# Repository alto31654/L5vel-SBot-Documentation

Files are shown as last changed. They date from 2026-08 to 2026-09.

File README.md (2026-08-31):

# L5vel-SBot-Documentation
This is my documentation of the work I have done on the SBots, including assembly guides, costs, set up guides, and 3D models

SUMMER SUMMARY:
For this summer semester, I had began new configurations for the SBOT's, including 1 arm with lift, dual arm, and 3 arm configurations. I have also retrofitted the first Sbot to have a lift.
I created an alternate version of the 3 arm base that is ready for assembly. I have also been working on improving the SetUp.md file within the SBot files to cover any missing steps
or to add in steps to do when certain issues arise. I have created assembly guides on how to build the robots from the ground up and how to configure the components within it.
I have also been developing the physical aspects of two bumper systems - one that is just a 3D printable cushion that goes on the corners of the robot, and one that detects when an impact occurs to actiate the E-Stop in the driving motors.
In my spare time, I am developing a shroud for the XArm 850s that will contain the wires for the external cameras and researching how to route the camera data through the arm itself to remove the reason for the shrouds in the first place.
I have also briefly worked with learning how to write code for a sensor I was trying to implement for the bumper; however, we ended up using a different sensor that doesn't need as much code.

There will be a file tree for each SBot's configuration assembly guide (i.e. single arm, dual arm, single arm with a lift, etc).
These are still a WIP

The CAD folder will contain all CAD files for all configurations of the SBot. This is because multiple configurations use the same parts. 
However there will be a folder for each configuration's assembly file. As of right now, there may be missing part errors when opening assemblies as the files are just copied.
I will reupload the files in a way to automatically fix this issue.
CAD assemblies are a WIP and will change with time.
Final versions of the Assembly Guides will include GitHub links to CAD files.

The cost breakdown sheet will continue to update as the project continues. Final versions of the Assembly Guides will include an appendix to incorporate this into one file.

The PC/Linux set up guide is a WIP and will be included in final versions of the Assembly Guides

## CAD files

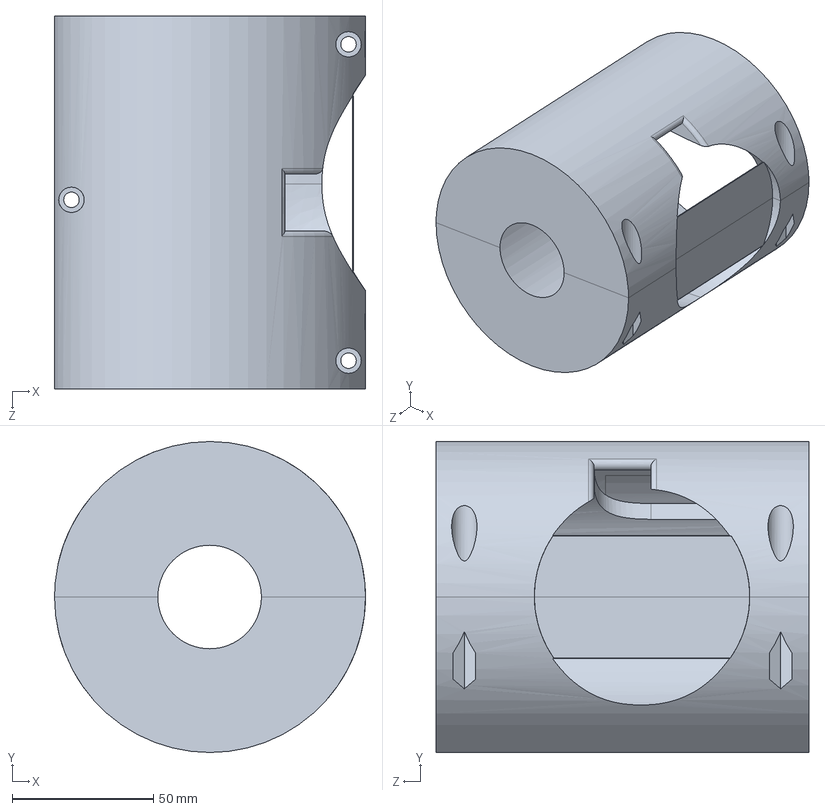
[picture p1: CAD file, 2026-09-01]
SBOT CAD Current/SBOT CAD Current/XArm850/J6CoverWhole.SLDPRT
110.0 x 110.0 x 131.9 mm

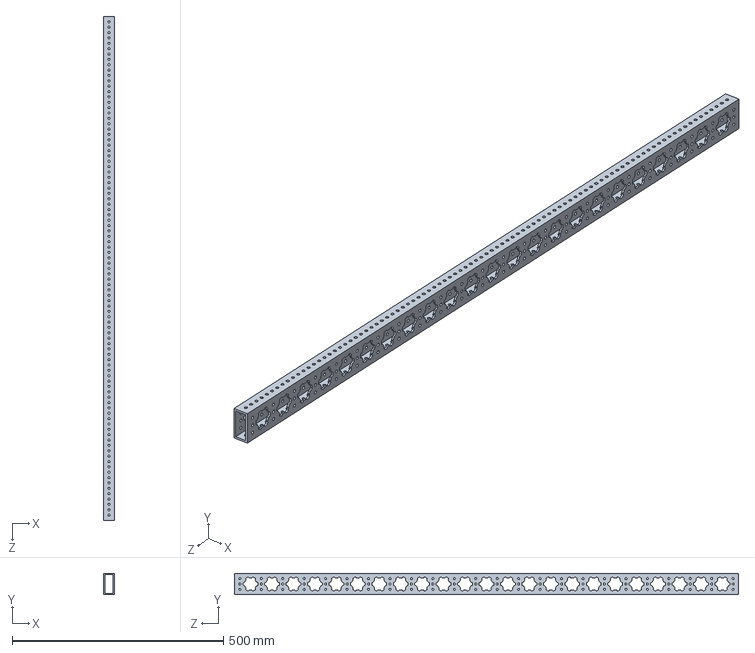
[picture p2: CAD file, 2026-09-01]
SBOT CAD Current/SBOT CAD Current/Hardware/MAXTube whole.STEP
25.4 x 50.8 x 1193.8 mm

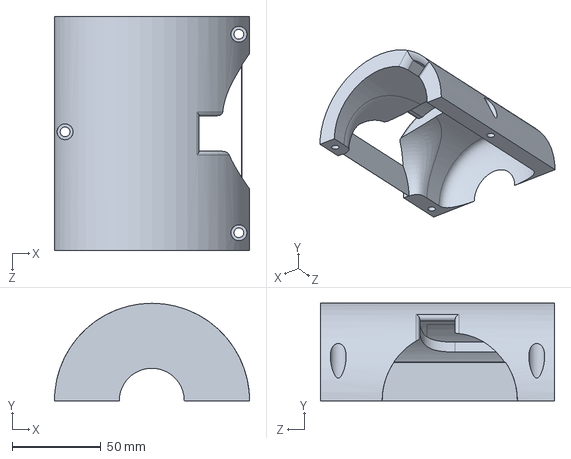
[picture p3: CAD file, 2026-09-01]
SBOT CAD Current/SBOT CAD Current/XArm850/J6Cover1WHoles.SLDPRT
110.0 x 55.0 x 131.9 mm

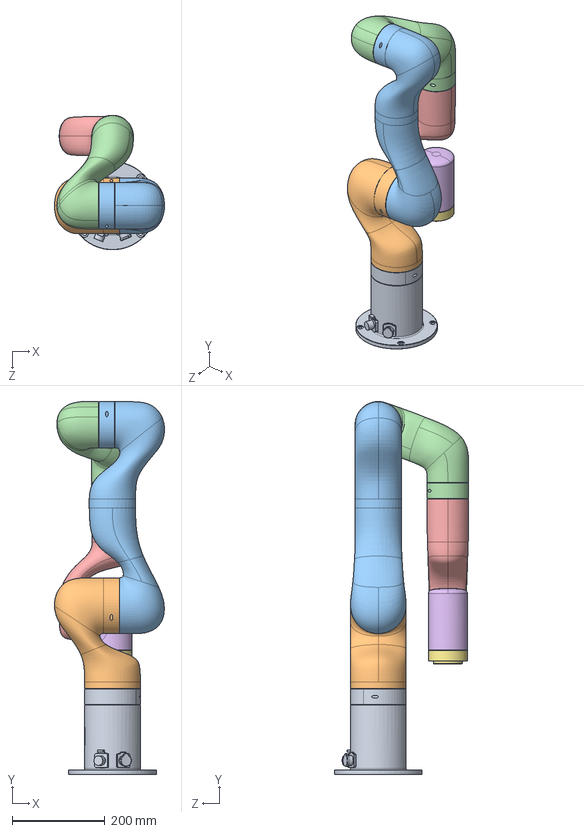
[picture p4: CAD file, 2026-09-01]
SBOT CAD Current/SBOT CAD Current/XArm850/UFACTORY-850-FX85xx-solidworks2016/FX85_M.SLDASM
237.2 x 804.1 x 289.8 mm
FX85_P01
FX85_P02
FX85_P03
FX85_P04
FX85_P05
FX85_P06
FX85_P07

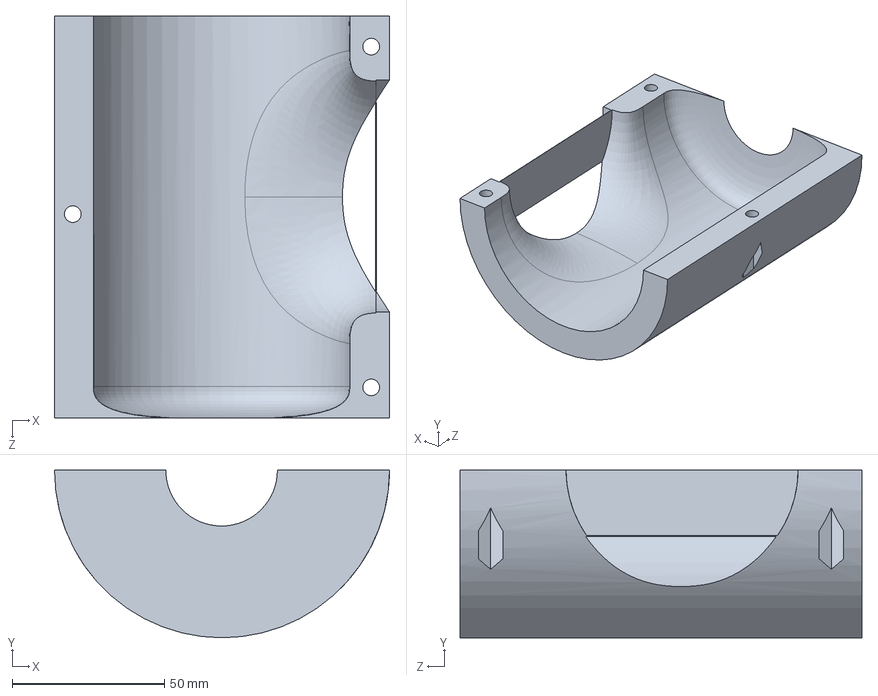
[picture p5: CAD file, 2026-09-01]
SBOT CAD Current/SBOT CAD Current/XArm850/J6CoverWHoles.SLDPRT
110.0 x 55.0 x 131.9 mm

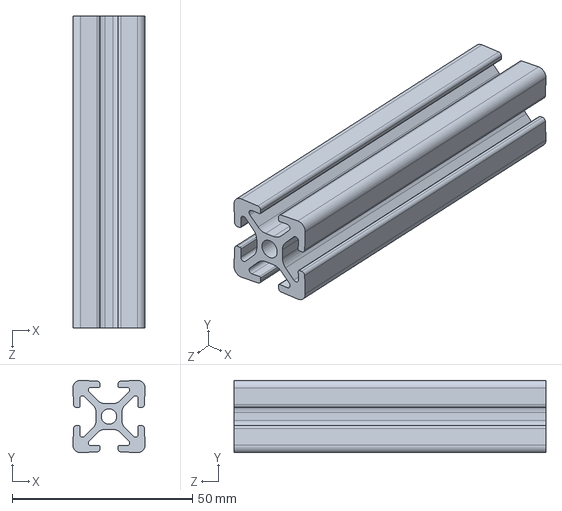
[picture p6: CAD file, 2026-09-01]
SBOT CAD Current/SBOT CAD Current/2020extrusion86_53mm.SLDPRT
20.0 x 20.0 x 86.5 mm

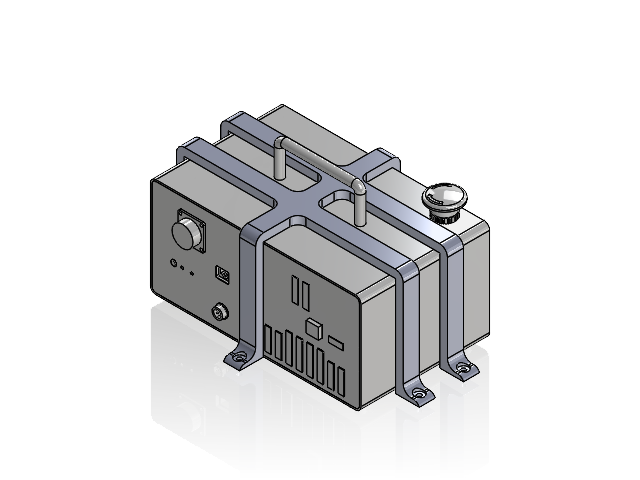
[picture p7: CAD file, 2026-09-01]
SBOT CAD Current/SBOT CAD Current/XArm7/CBMount.SLDASM
AC Control Box Pro(7)
Mount^CBMount

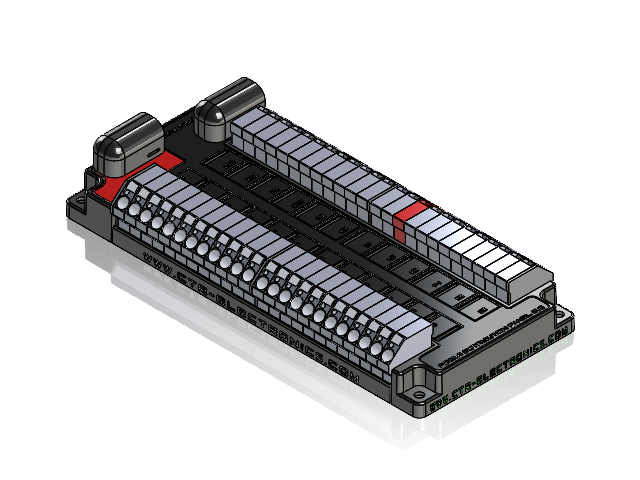
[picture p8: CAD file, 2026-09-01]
SBOT CAD Current/SBOT CAD Current/Hardware/Electronics/PDP 2.0 CAD (1)/PDP_2.0_release.SLDASM
PDP_2.0_NO BREAKERS.STEP
terminal with cover_1.STEP x 2

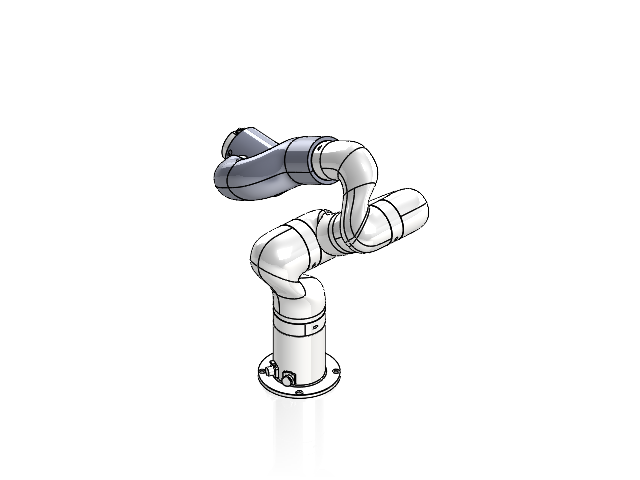
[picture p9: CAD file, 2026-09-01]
SBOT CAD Current/SBOT CAD Current/XArm850/CableCoverAssem.SLDASM
FX85_P01
FX85_P02
FX85_P03
FX85_P04
FX85_P05
FX85_P06
FX85_P07
J6CoverWhole
J5Cover

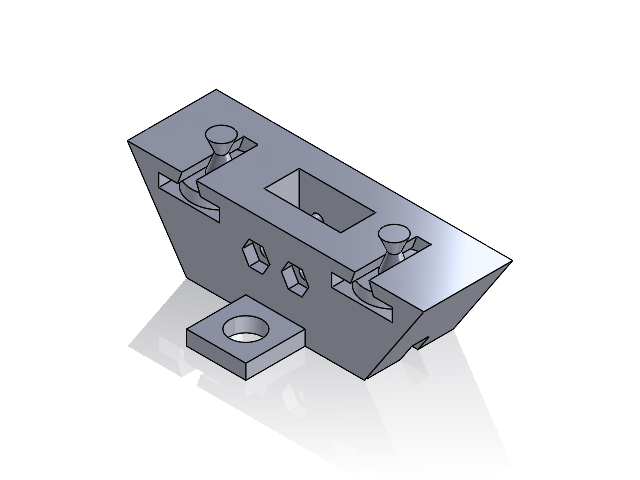
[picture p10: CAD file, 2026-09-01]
SBOT CAD Current/SBOT CAD Current/Hardware/Bumpers/BumpStopAssem.SLDASM
SwitchBumpStop
TPUBumpStop x 2

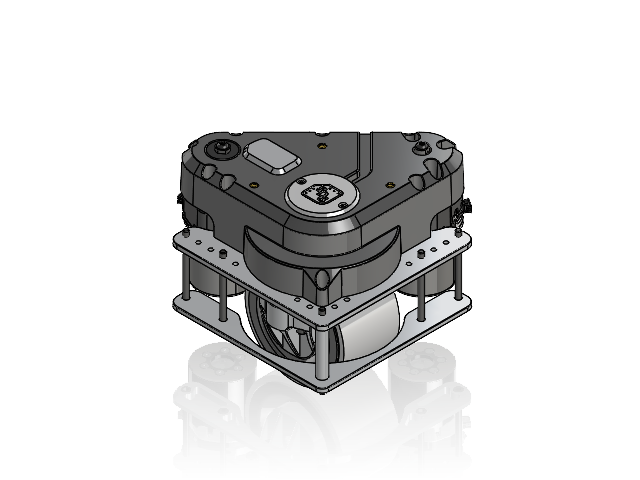
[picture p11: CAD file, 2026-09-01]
SBOT CAD Current/SBOT CAD Current/Hardware/SwerveAssem.SLDASM
MK5i
ISDF-05-D-M_b.STEP x 2
SFSX-RL.STEP x 4
TFM-105-02-L-DH_pins.STEP x 2
TFM-105-02-L-DH_terminal.STEP x 2
USB4110-GF-A_PART1.STEP x 2
REV-11-2159-P01.STEP x 2
REV-11-2159-P11.STEP x 6
REV-11-2159-P02.STEP x 2
REV-11-2159-P04_95893A164.STEP x 4
0.8BTB male 7.5H 2X10P--No side positioning plate.STEP x 2
EVQP7-JA-01P.STEP x 2
REV-11-2159-P09_92832A108.STEP x 16
REV-21-1652-P13.STEP x 2
REV-21-1652-P12.STEP x 6
REV-21-1652-P02.STEP x 2
REV-21-1652-P08.STEP x 2
Screw_M3x5mm_91294A125_Flat_Head_91294A125.STEP x 12
97145A104_Single-Turn Spiral External Retaining Ring_97145A104.STEP x 2
REV-21-1652-P01.STEP x 2
Bearing_17mmID_30mmOD_6656K196_6656K196.STEP x 2
0.8BTB female 9.0H 2X10P - With side positioning plate.STEP x 2
REV-21-1652-P10.STEP x 2
REV-21-3204.STEP x 8
REV-21-2807.STEP x 2
REV-21-2805.STEP x 2

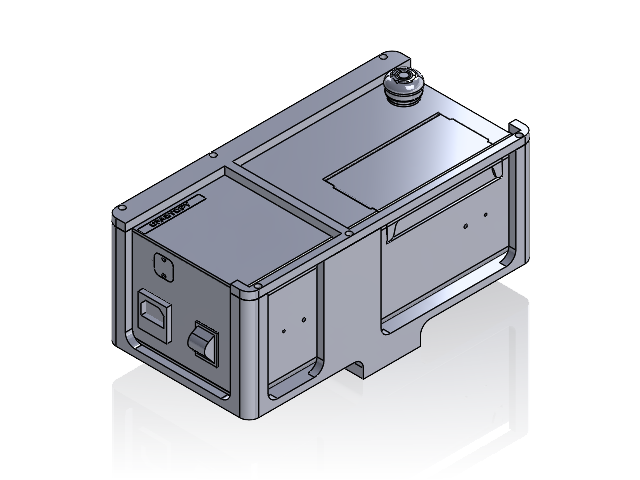
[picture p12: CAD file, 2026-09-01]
SBOT CAD Current/SBOT CAD Current/XArm7/ControlBox7MountAssem.SLDASM
AC Control Box(AC1300)(7)
ControlBox7Holder
CBHolderLid

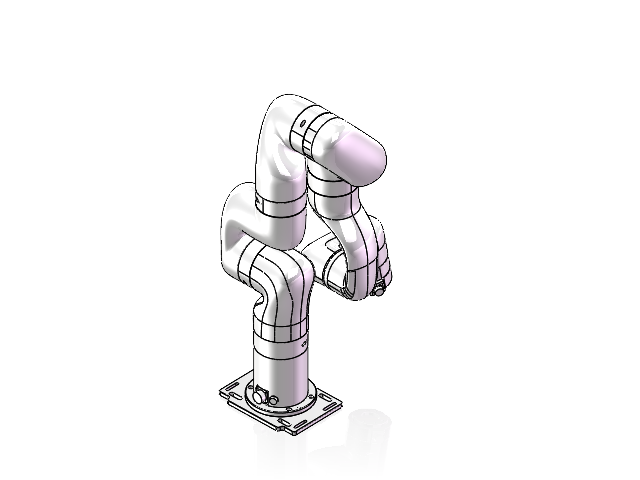
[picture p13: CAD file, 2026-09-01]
SBOT CAD Current/SBOT CAD Current/XArm7/xArm-7-XS1305-solidworks2016/XS1305_M.SLDASM
XS1305_P01
XS1305_P02
XS1305_P03
XS1305_P04
XS1305_P05
XS1305_P06
XS1305_P07
XS1305_P08

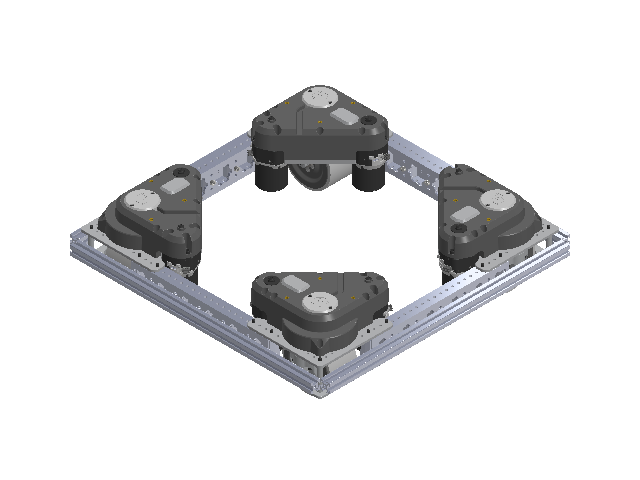
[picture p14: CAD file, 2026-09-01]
SBOT CAD Current/SBOT CAD Current/Hardware/SwerveSquare.SLDASM
MK5i x 4
ISDF-05-D-M_b.STEP x 8
SFSX-RL.STEP x 16
TFM-105-02-L-DH_pins.STEP x 8
TFM-105-02-L-DH_terminal.STEP x 8
USB4110-GF-A_PART1.STEP x 8
REV-11-2159-P01.STEP x 8
REV-11-2159-P11.STEP x 24
REV-11-2159-P02.STEP x 8
REV-11-2159-P04_95893A164.STEP x 16
0.8BTB male 7.5H 2X10P--No side positioning plate.STEP x 8
EVQP7-JA-01P.STEP x 8
REV-11-2159-P09_92832A108.STEP x 64
REV-21-1652-P13.STEP x 8
REV-21-1652-P12.STEP x 24
REV-21-1652-P02.STEP x 8
REV-21-1652-P08.STEP x 8
Screw_M3x5mm_91294A125_Flat_Head_91294A125.STEP x 48
97145A104_Single-Turn Spiral External Retaining Ring_97145A104.STEP x 8
REV-21-1652-P01.STEP x 8
Bearing_17mmID_30mmOD_6656K196_6656K196.STEP x 8
0.8BTB female 9.0H 2X10P - With side positioning plate.STEP x 8
REV-21-1652-P10.STEP x 8
REV-21-3204.STEP x 32
REV-21-2807.STEP x 8
REV-21-2805.STEP x 8
MAXTube Cut x 4
MAXTubeSupport x 28
2020extrusion510mm x 4
SpringLoadedTNut x 12
M5x30mm18-8SocketScrew x 12

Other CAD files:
SBOT CAD Current/SBOT CAD Current/Hardware/CBBracket.SLDASM
SBOT CAD Current/SBOT CAD Current/Hardware/MotorAssem.SLDASM
SBOT CAD Current/SBOT CAD Current/sbotFrame.SLDASM
SBOT CAD Current/SBOT CAD Current/Hardware/Electronics/BatteryWithCornerMounts.SLDASM
SBOT CAD Current/SBOT CAD Current/2020extrusion100mm.SLDPRT
SBOT CAD Current/SBOT CAD Current/2020extrusion84_85mm.SLDPRT
SBOT CAD Current/SBOT CAD Current/Hardware/Brackets/135Bracket.SLDPRT
SBOT CAD Current/SBOT CAD Current/Hardware/Brackets/45Bracket.SLDPRT
SBOT CAD Current/SBOT CAD Current/Hardware/Brackets/CornerBracket.SLDPRT
SBOT CAD Current/SBOT CAD Current/Hardware/Bumpers/BallCornerBumper.STL
SBOT CAD Current/SBOT CAD Current/Hardware/Bumpers/BigCornerBumper.SLDPRT
SBOT CAD Current/SBOT CAD Current/Hardware/Bumpers/BigCornerBumper.STL
SBOT CAD Current/SBOT CAD Current/Hardware/Bumpers/SwitchBumpStop.SLDPRT
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

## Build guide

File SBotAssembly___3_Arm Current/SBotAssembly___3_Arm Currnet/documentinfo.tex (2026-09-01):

%------------------------------------------------
% Document Information
%------------------------------------------------

\newcommand{\DocTitle}{S-Bot Assembly Guide}

\newcommand{\DocSubtitle}{Mechanical Assembly and Configuration Manual}

\newcommand{\DocConfig}{Three Arm Configuration}

\newcommand{\DocNumber}{L5-SB-003}

\newcommand{\DocVersion}{1.0.0}

\newcommand{\DocRevision}{A}

\newcommand{\DocDate}{July 2026}

\newcommand{\Authors}{Johns, William}

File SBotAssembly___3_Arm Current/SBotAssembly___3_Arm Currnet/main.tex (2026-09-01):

\documentclass[11pt]{article}

\input{preamble}
\input{styles}
\input{documentinfo}

\author{}
\date{}

\begin{document}

\input{titlepage}

\pagenumbering{roman}
\tableofcontents
\clearpage

\pagenumbering{arabic}

\input{sections/motor_assembly}
\clearpage

\input{sections/swerve_module}
\clearpage

\input{sections/motor_setup}
\clearpage

\input{sections/power_distribution}
\clearpage

\input{sections/canivore}
\clearpage

\input{sections/base_bottom}
\clearpage

\input{sections/base_middle}
\clearpage

\input{sections/base_top}
\clearpage

\appendix
\input{appendices/motor_config_appen}

\end{document}

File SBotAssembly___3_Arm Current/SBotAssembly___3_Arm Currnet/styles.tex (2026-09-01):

% Colors
\definecolor{sbotblue}{HTML}{1F4E79}
\definecolor{sbotlightblue}{HTML}{EAF3FA}
\definecolor{sbotgray}{HTML}{F4F4F4}

% Callout boxes
\newtcolorbox{partsbox}{
colback=sbotlightblue,
colframe=sbotblue,
title=Required Parts,
fonttitle=\bfseries
}

\newtcolorbox{warningbox}{
colback=yellow!10,
colframe=orange!80!black,
title=Important,
fonttitle=\bfseries
}

\newtcolorbox{tipbox}{
colback=sbotgray,
colframe=gray,
title=Tip,
fonttitle=\bfseries
}

\titleformat{\section}
{\Large\bfseries\color{sbotblue}}
{\thesection}{0.75em}{}
[\titlerule]

\titleformat{\subsection}
{\large\bfseries\color{sbotblue}}
{\thesubsection}{0.75em}{}

% Better spacing
\setlength{\parindent}{0pt}
\setlength{\parskip}{6pt}
\setlist[itemize]{topsep=3pt,itemsep=2pt}

% Headers/footers
\pagestyle{fancy}
\fancyhf{}
\lhead{S-Bot Assembly Guide}
\rhead{\leftmark}
\cfoot{\thepage}

% Image safety
\makeatletter
\def\maxwidth{\ifdim\Gin@nat@width>\linewidth\linewidth\else\Gin@nat@width\fi}
\def\maxheight{\ifdim\Gin@nat@height>0.85\textheight 0.85\textheight\else\Gin@nat@height\fi}
\makeatother
\setkeys{Gin}{width=\maxwidth,height=\maxheight,keepaspectratio}

%------------------------------------------------
% Table of Contents Styling
%------------------------------------------------

\renewcommand{\contentsname}{Table of Contents}

\setlength{\cftbeforesecskip}{6pt}
\setlength{\cftbeforesubsecskip}{2pt}

\renewcommand{\cftsecfont}{\bfseries\color{sbotblue}}
\renewcommand{\cftsecpagefont}{\bfseries\color{sbotblue}}

\renewcommand{\cftsubsecfont}{\normalfont}
\renewcommand{\cftsubsecpagefont}{\normalfont}

\renewcommand{\cftsecleader}{\cftdotfill{\cftdotsep}}

%------------------------------------------------
% Assembly Step Styling
%------------------------------------------------

\newcounter{assemblystep}

\newcommand{\resetassemblysteps}{%
    \setcounter{assemblystep}{0}
}

\newcommand{\assemblystep}[1]{%
    \refstepcounter{assemblystep}
    \vspace{0.6cm}
    {\large\bfseries\color{sbotblue}Step \theassemblystep: #1\par}
    \vspace{0.15cm}
    \noindent\color{sbotblue}\rule{\textwidth}{0.5pt}
    \color{black}
    \vspace{0.25cm}
}

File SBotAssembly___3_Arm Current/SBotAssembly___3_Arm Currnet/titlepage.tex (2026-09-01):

\begin{titlepage}

\thispagestyle{empty}
\centering

%------------------------------------------------
% Top spacing
%------------------------------------------------

\vspace*{1.5cm}

%------------------------------------------------
% Title
%------------------------------------------------

{\Huge\bfseries\color{sbotblue}\DocTitle\par}

\vspace{0.35cm}

{\Large\DocSubtitle\par}

\vspace{0.25cm}

{\Large\bfseries\color{sbotblue}\DocConfig\par}

\vspace{0.75cm}

\color{sbotblue}
\rule{0.8\textwidth}{1.5pt}
\color{black}

\vspace{1cm}

%------------------------------------------------
% Robot Image
%------------------------------------------------

% Uncomment once you have a good image
%
% \includegraphics[width=0.70\textwidth]{images/sbot_overview.png}
%
% OR use your CAD render instead

\vfill

%------------------------------------------------
% Document Information
%------------------------------------------------

\renewcommand{\arraystretch}{1.4}

\begin{tabular}{rl}
\textbf{Document ID:} & \DocNumber \\
%\textbf{Configuration:} & \DocConfig \\
\textbf{Version:} & \DocVersion \\
%\textbf{Revision:} & \DocRevision \\
\textbf{Date:} & \DocDate \\
\textbf{Written by:} & \Authors \\
\end{tabular}

%\vfill

{\Large L5VEL}

\vspace{0.3cm}

%{\small Internal Documentation}

\end{titlepage}

\clearpage

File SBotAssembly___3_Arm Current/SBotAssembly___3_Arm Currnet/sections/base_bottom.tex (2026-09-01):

\section{Base Assembly -- Bottom Layer}
\resetassemblysteps

\begin{partsbox}
\begin{minipage}[t]{\linewidth}
\vspace{0pt}
\begin{itemize}
\item
  4 Assembled Swerve Modules
\item
  1
  \href{https://www.bestbuy.com/product/anker-solix-c1000x-gen2-portable-power-station-2000w-1024-wh-capacity-dark-gray/JJ858RLLVK}
  {Anker Solix C1000x Gen 2}
\item
  1 A/C Control Boxes
\item
  2 \href{https://www.revrobotics.com/MAXTube-2x1/}
  {2"x1"x47" - 1/8" MAXTube Channel} -
  \href{https://revrobotics.com/content/cad/REV-21-3580.STEP}{STEP}
\item
  1 \href{https://www.revrobotics.com/maxtube-internal-supports/}
  {30 pack MAXTube Internal Support} -
  \href{https://revrobotics.com/content/cad/REV-21-3620.STEP}{STEP}
\item
  10
  \href{https://www.amazon.com/Aluminum-Extrusion-European-Standard-Anodized/dp/B0CJ2444RP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\&dib=eyJ2IjoiMSJ9.PZ2FPe9mMeh2RjmXCOARMJXrWmDwBK7v6pNs8rNSyqoPpPKsgh7tF6KNxYk9Ar6jRMz0ZAwxM4tbQfzEnDNLSBNuQv6MKW9yA_1ZpzTuvs6cmNikscEC3qR-9UYQdLuWI9VPNDXBrewSK4GJfKpK7OGRP678XPT5gkdxunE0mi17g96SjQU3kdsGpMGbod45Zct9aVPBfKQaI-vDfUCWijtkFxV_eApHlAQB2atX4vw.g0drfgF2Qlq6SmjnSINZo8Rp1Ej7S_yfQs0q05EGSqg\&dib_tag=se\&keywords=10\%2Bpcs\%2B800mm\%2BT\%2BSlot\%2B2020\%2BAluminum\%2BEXtrustion\%2BEuropean\%2BStandard\%2BAnodized\%2BLinear\%2BRail\%2BPENGLONG\&nsdOptOutParam=true\&qid=1780009034\&sprefix=10\%2Bpcs\%2B800mm\%2Bt\%2Bslot\%2B2020\%2Baluminum\%2Bextrustion\%2Beuropean\%2Bstandard\%2Banodized\%2Blinear\%2Brail\%2Bpenglong\%2Caps\%2C105\&sr=8-2\&th=1}
  {20x20x800mm T-Slot Aluminum Extrusion}
  \item
  1
  \href{https://a.co/d/00U2xDgu}
  {2x1x12" Aluminum Extrusion}
\item
  8
  \href{https://www.amazon.com/2020-Bracket-Aluminum-Extrusion-Connector/dp/B0B15LWB96/ref=sr_1_4?crid=GBX1DKP7GAGY\&dib=eyJ2IjoiMSJ9.YwZZJkrg4tHSDQtAhQFm_xWTziZvc73fSAx6Xu3V0eU9Pqt2kpgHOMdfl-j03eXqLr9SqVJYsOjBRsPwTCeRLPtVxaWp92QOj3YkpEqxe_f8uoBLlCDSbJNoPuO7oEmj38Xk2B-rbRdMmVb4LCTjK_d-28hle0DLks3O0dHpkuvaCBjan9vx2tdJSw9iC-mnxOK3t7UgCEoea3K5irfrMBFTM5oumf1ZcDhywTPPYWw._AcCkrgnzVeJorywdvUhORfM7Ll_8HjaW-XAmTmjHmU\&dib_tag=se\&keywords=10\%2Bpcs\%2B2020\%2Bcorner\%2Bbracket\%2Bjoint\%2Bplate\%2Bbaykailin\&nsdOptOutParam=true\&qid=1780009641\&sprefix=10\%2Bpcs\%2B2020\%2Bcorner\%2Bbraket\%2Bjoint\%2Bplate\%2Bbaykailin\%2Caps\%2C145\&sr=8-4\&th=1}
  {L Shape Corner Plates}
\item 
  4
  \href{https://a.co/d/06DF40PH}
  {T Shape Plates}
\item
  16
  \href{https://www.amazon.com/32Pcs-Bracket-Aluminum-Extrusion-Industrial/dp/B0C19C1G8W/ref=sr_1_2?crid=2ZFRAXDPV6K9C\&dib=eyJ2IjoiMSJ9.9llDtPZ6rC_p4rDCn1uyFMxeYyRqWBqgLth9R1QRUb9haw9tHsyhizxJVyQVEJX5E5PHdfHeTqni3lrNDXwIjGCy2CiyC60eyHkbztAObX37nNxon_ILhSnd09eTZLvc84vumvQUyfKhNQYpPDhZgRcfddb-_4-e74BTyMMXhbZpMVmt0jbXza8zo7j_JoYYlt-aRjExxcLoMb4P7yTEhUpbAyACgTkJjVQYmn20FDY.kABSI1pFjrAhVJf0W1q_K6ofkuv8qBnGbZljKoPPBOA\&dib_tag=se\&keywords=32\%2Bpcs\%2Bcorner\%2Bbracket\%2B(20x17)\%2B2020\%2BNVAXQF\&qid=1780009800\&sprefix=32\%2Bpcs\%2Bcorner\%2Bbracket\%2B20x17\%2B2020\%2Bnvaxqf\%2Caps\%2C154\&sr=8-2\&th=1}
  {Corner Brackets}
\item 
  2
  \href{https://a.co/d/04PJysob}
  {45\textdegree/135\textdegree Angle Brackets} 
\item
  4
  \href{https://www.amazon.com/Connector-European-Standard-Aluminum-Extrusion/dp/B08C9Q2TGW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\&dib=eyJ2IjoiMSJ9.XlFn0FUD_8bCmwRRsrK3ogoBM9pDYnXxPWb7pYhDUtpbaBdLS8JCgUwpbQRowJIBRGu7SUeTHqtP1eBtSTiS18Sg84w_ihJPsVWvAMiteSHIzFL2oHRrPM4m8CAJ-ks8sh8j5DC-wP7l_XGKElRn3GHssF1H0BJaBYMlbejWc5FgyIl1I2W_iTsWiMzd4AI7nCJLSuzAJ6M40i4CYv-TYfnSxv07gNfMx5ZabKKs8aw.XCs7Hk74AdpQPvURhkJcwiumf4aajQdL3EV2vXkkcQc\&dib_tag=se\&keywords=8pcs\%2B2020\%2Baluminum\%2Bextrustion\%2Bt\%2Bslot\%2Bcorner\%2Bbracket\%2B3\%2Bway\%2Btri\%2Bconnector\%2BBLCCLOY\&nsdOptOutParam=true\&qid=1780010034\&sprefix=8pcs\%2B2020\%2Baluminum\%2Bextrustion\%2Bt\%2Bslot\%2Bcorner\%2Bbracket\%2B3\%2Bway\%2Btri\%2Bconnector\%2Bblccloy\%2Caps\%2C121\&sr=8-3\&th=1}
  {Tri-Connectors}
\item
  118
  \href{https://www.amazon.com/100-Pack-Aluminum-Extrusions-Profile-Accessories/dp/B07VHNGBWJ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\&dib=eyJ2IjoiMSJ9.5erSjcFGuqxSi7i2L21rT0vbw0ytuhxrp2ltZMOLJ8UqIwudlyaYHt6ZpRlbWvk8FE864dYDJ1VLjjJk06LhvL07sQfFYWLzdZL2KVXkDSPyUpj40WzXATJ8pfYO-zARlj70J7cKX5n7kSFpZu9gwaq8QH-tRelX3ksKgh7TlIR0J96mfletc1Kltj1N9UXhiUmpMmKqw3YiYb35hBPuc4xUwdT7UsevWwIn2pnDoC0.3xr-5AQMwqWdX2mbf9nYZ-dcUiSk-N2MZR-ugnD5pTw\&dib_tag=se\&keywords=100-pack\%2B2020\%2Broll\%2Bin\%2Bspring\%2Bloaded\%2Bt\%2Bnut\%2Bm5\%2BPOLISI3D\&nsdOptOutParam=true\&qid=1780010876\&sprefix=100-pack\%2B2020\%2Broll\%2Bin\%2Bspring\%2Bloaded\%2Bt\%2Bnut\%2Bm5\%2Bpolisi3d\%2Caps\%2C142\&sr=8-3\&th=1}
  {Spring Loaded M5 T-Nuts}
\item
  82
  \href{https://www.amazon.com/SVLING-175PCS-Button-Socket-Spanner/dp/B0FY5V1MPV/ref=sr_1_3?crid=GD2UCGPO1OVK\&dib=eyJ2IjoiMSJ9.tz2hSSl2Ko7I26DlEqA0mgjFOTYWZVyXkZOq0TCaByptr6KbeIy5LjmCNKtSxXotJ40yMGtu911TcFvMq0lGVkDBizgWGzuMKf9cWYvgSg6MYah47H1GVJieTB7XXt9ff_UrymOopVPVZhsQ43j2CPIbsql8_NvrnjpWMGIhZEjiU2ySpVBKEtTZuLau4a4svmc2pzIAvlywjPajTNJJAWlpVt8YTIPqh1EQDcE9mJ0.i4abLXgOdvPijXQszcI-ovrsFf_kOuUGIbLAR9xh9WA\&dib_tag=se\&keywords=m5x8mm\%2B175pcs\%2Bbutton\%2Bhead\%2Bsocket\%2Bcap\%2Bscrew\%2Bbolts\%2BSVLING\&nsdOptOutParam=true\&qid=1780011697\&sprefix=m5x8mm\%2B175pcs\%2Bbutton\%2Bhead\%2Bsocket\%2Bcap\%2Bscrew\%2Bbolts\%2Bsvling\%2Caps\%2C128\&sr=8-3\&th=1}
  {Button Head M5x8mm Machine Screws}
\item
  22
  \href{https://a.co/d/0beRFsAu}
  {Button Head M5x10mm Machine Screws}
\item
  12 
  \href{https://www.mcmaster.com/91292a192/}
  {M5x30mm Machine Screws}
\item
  4
  \href{https://a.co/d/0hDeyVaw}
  {M5x55mm Socket head Machine Screws} 
\item
  8 M5 Washers
\item
  2 M5 Nuts
\item
  1
  \href{https://www.amazon.com/Loctite-242-Threadlocker-Liquid-1-69oz/dp/B002P8LQ1C/ref=sr_1_4?crid=1C7SLWXA3HNCF\&dib=eyJ2IjoiMSJ9.7OmIx_oDHsONqWbeidNiSrahsI0Km1SsrNH3D-gyuZNfhTT6fuPz-yxpn6ouyWCmNM6CYg6vC_Vwy65nIwSK1Zk51und6wQn-HBHnxvXSz_HK_Ug496ZmvlwSMH0ThO-fFtpz10DXtIVyznYEHlvFjtMq0vzz7dSyhbQaQ1VxxJAWf0jfW4wgc0CZbspWrNj9wj5RVRE5bh1iz6qJ_w8ki7GWFobgrXoJeNJ2M0ao4LMAlM5zlhJxdQqxtc9te0Q7sO6Vhc9_SeBVJMOXptmM-4TMQdzEPjVM4bTiYMuMtw.KKRsu1AubScYRtEjyD0dvZ9Ou056x5yyAdyc4josUng\&dib_tag=se\&keywords=Loctite+242\&qid=1780011409\&sprefix=loctite+242\%2Caps\%2C172\&sr=8-4}
  {Bottle Loctite}
\item
  2
  \href{https://www.amazon.com/Fondwell-Adjustable-Reinforced-Internal-Tie-Downs/dp/B0CC55TP9P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\&dib=eyJ2IjoiMSJ9.tKxN_u-fARPeq3NN7oKUvKFmazhBJgR5wCeEcW3RRpU.Z9UEwgguOvz_g9mCpK3gWCWXdqGQbj6VpLNOE-pqfa4\&dib_tag=se\&keywords=Fondwell\%2Bhigh-quality\%2B1\%2F8\%22rope\%2Bhangers\&qid=1780012484\&sprefix=fondwell\%2Bhigh-quality\%2B1\%2F8\%2Brope\%2Bhangers\%2Caps\%2C116\&sr=8-1\&th=1}{1/8''
  Ratcheting Rope Hangers}

\end{itemize}
\end{minipage}
\end{partsbox}

\assemblystep{Prepare the 2x1 Channels}
Cut the 2x1 MAXTube to 288mm. The outer most edge of the holes on the 1
inch side of the channel should be 1.5mm away from the edge with a 0.5mm
tolerance. The larger holes on the 2 inch side will be at the start and
end of the piece of the channel. The edge of these holes will most
likely be cut off. Insert 7 internal support pieces, 1 on each end and 1
at each set of holes on the 2'' side.

\begin{figure}[H]
\centering
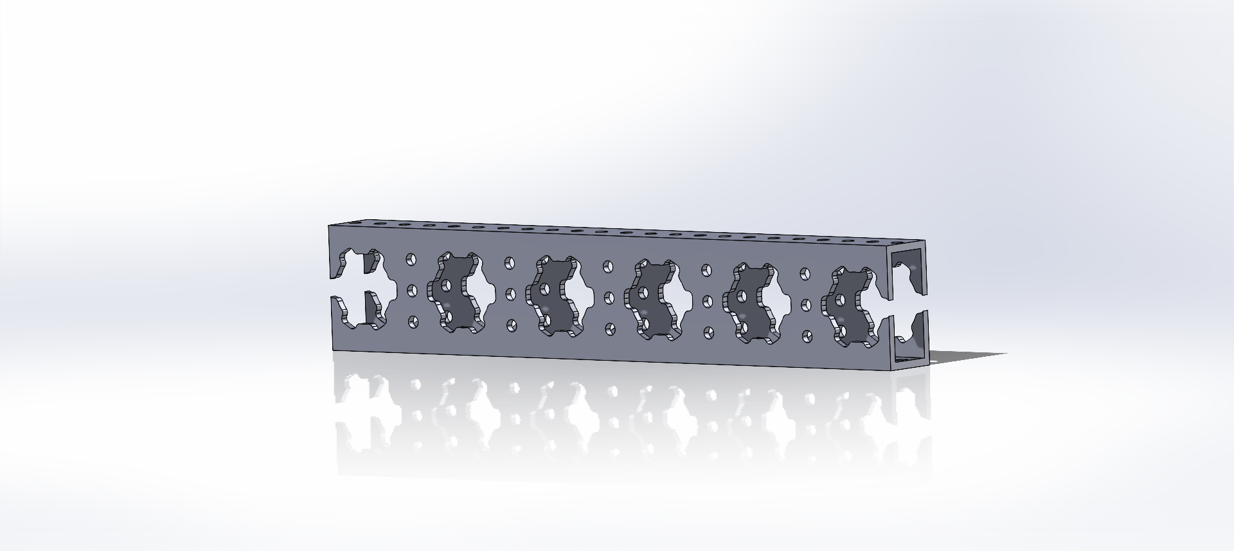
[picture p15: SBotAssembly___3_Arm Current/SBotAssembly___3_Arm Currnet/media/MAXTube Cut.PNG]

\hfill
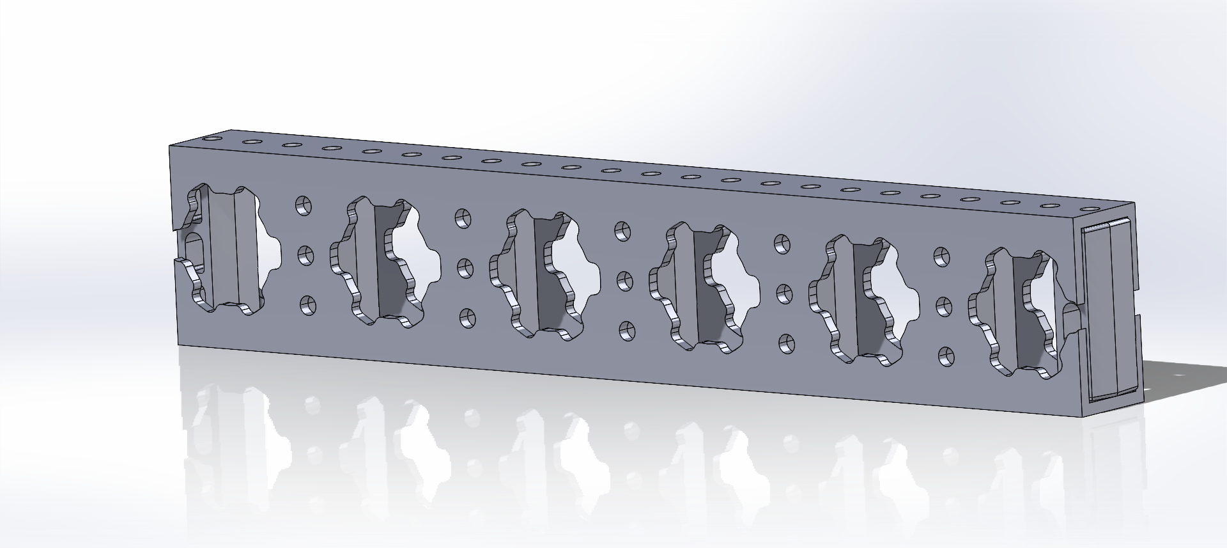
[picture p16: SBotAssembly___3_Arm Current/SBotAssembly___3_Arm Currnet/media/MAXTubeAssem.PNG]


\caption{The cut 2×1 MAXTube with internal supports seated at each end and hole set.}
\end{figure}

\assemblystep{Build the Base Frame}
Place 3 T-Nuts in one side of 4 508mm extrusions. Add a
drop of Loctite to the end of 3 30mm screws and attach the 2x1 channel
using the center three sets of holes. Do not tighten until the base is
properly aligned. Repeat these steps 3 more times.

\begin{figure}[H]
\centering
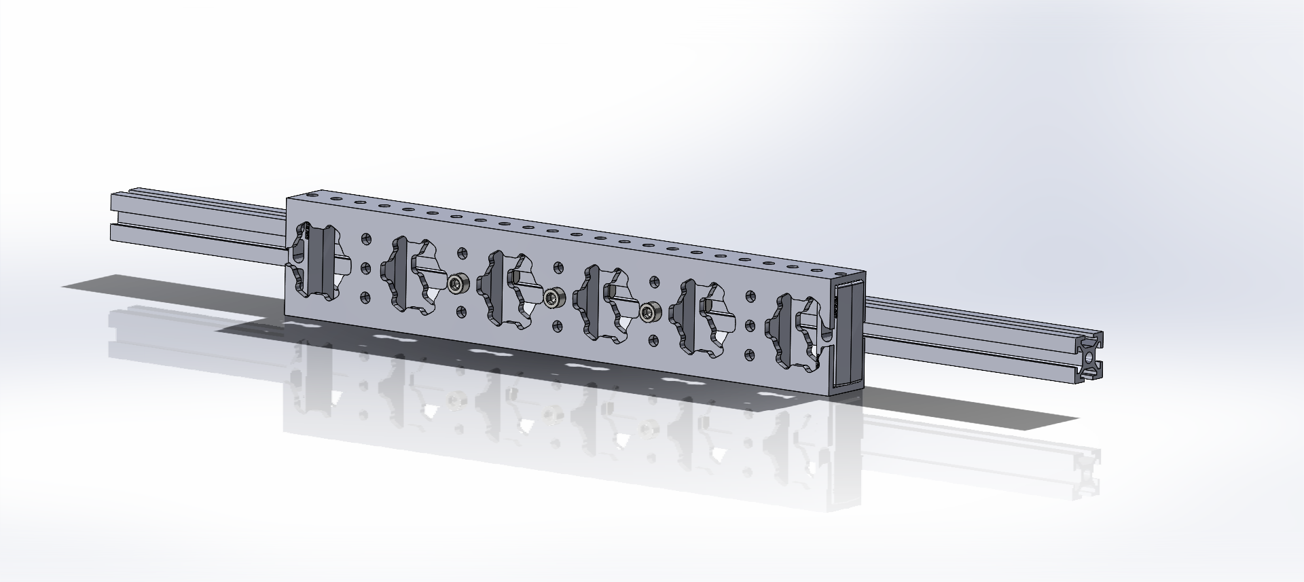
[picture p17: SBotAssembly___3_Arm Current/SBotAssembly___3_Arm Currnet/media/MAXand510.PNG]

\caption{Attaching a 20x20mm extrusion to the 2x1 channel through the
center hole sets.}
\end{figure}

\assemblystep{Mount the Swerve Modules}
Remove the 2 long bolts on each side of the swerve modules and slide the
2x1 channel between the two plates. Secure with the bolts that were just
removed. Be sure to add Loctite to the ends of these bolts and secure
tightly. Repeat until the modules are assembled in a square. Add the
Tri-Connectors to the 20x20mm extrusions with the 2-pronged side facing
upwards.

\begin{figure}[H]
\centering
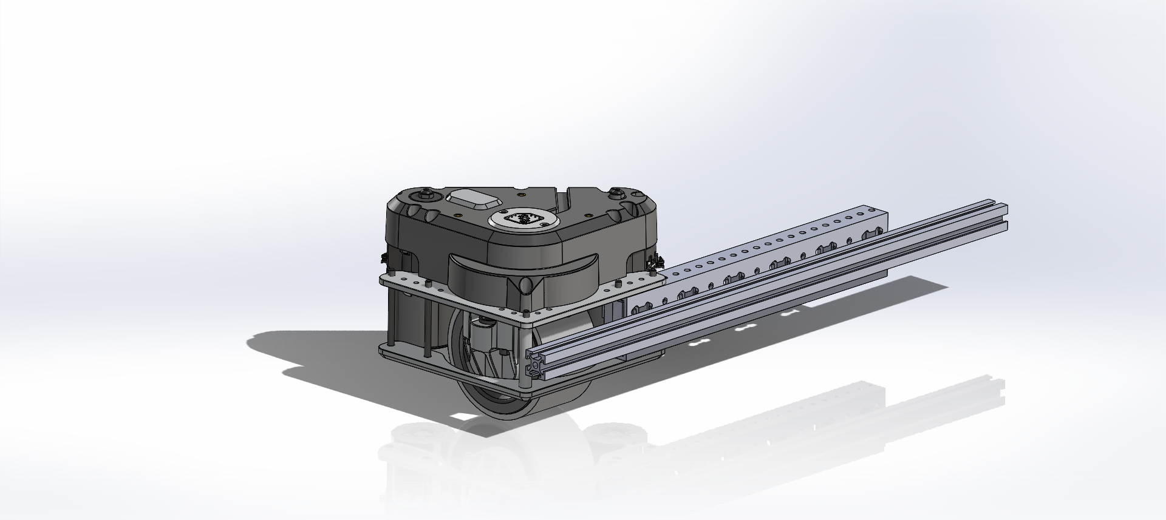
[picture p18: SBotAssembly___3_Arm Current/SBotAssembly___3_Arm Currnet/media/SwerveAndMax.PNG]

\hfill
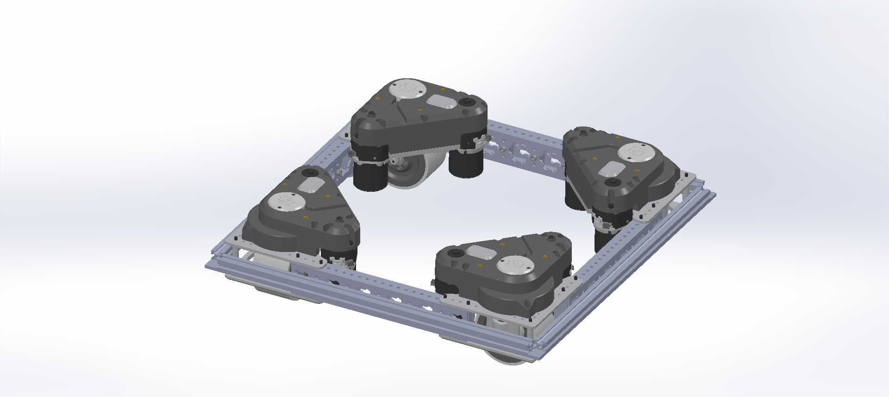
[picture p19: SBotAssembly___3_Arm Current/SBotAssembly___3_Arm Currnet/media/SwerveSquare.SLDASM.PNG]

\caption{Sliding the 2x1 channels between the swerve module plates and
adding the Tri-Connectors.}
\end{figure}

\assemblystep{Install the Vertical Extrusions}
Vertically install 4 400mm extrusions, one at each corner. Tighten the set
screws.

\begin{figure}[H]
\centering
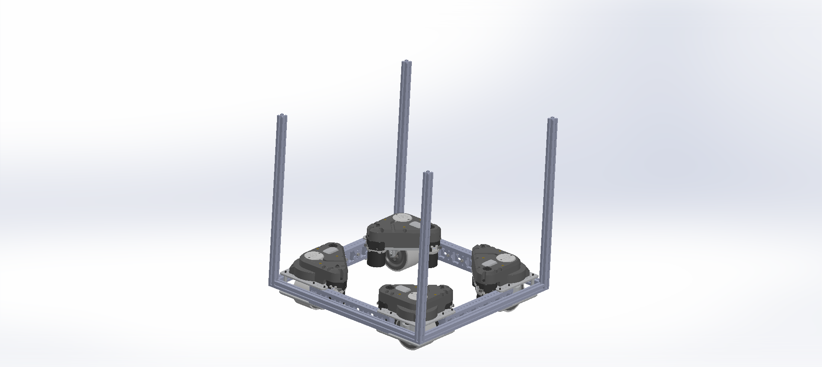
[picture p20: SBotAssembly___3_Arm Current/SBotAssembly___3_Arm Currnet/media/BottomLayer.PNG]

\caption{A vertical 20x20mm extrusion installed at a corner via the
Tri-Connector.}
\end{figure}

Make sure the four extrusions are aligned properly and add the set pins
to the Tri-Connectors. Then tighten the M5x30mm bolts going through the
2x1'' channel.

\assemblystep{Install Corner Brackets}
Install a corner bracket at each 90 degree angle. Each one will use two
T-Nuts and two M5x8mm button head screws. Be sure to secure with
Loctite.

\begin{figure}[H]
\centering

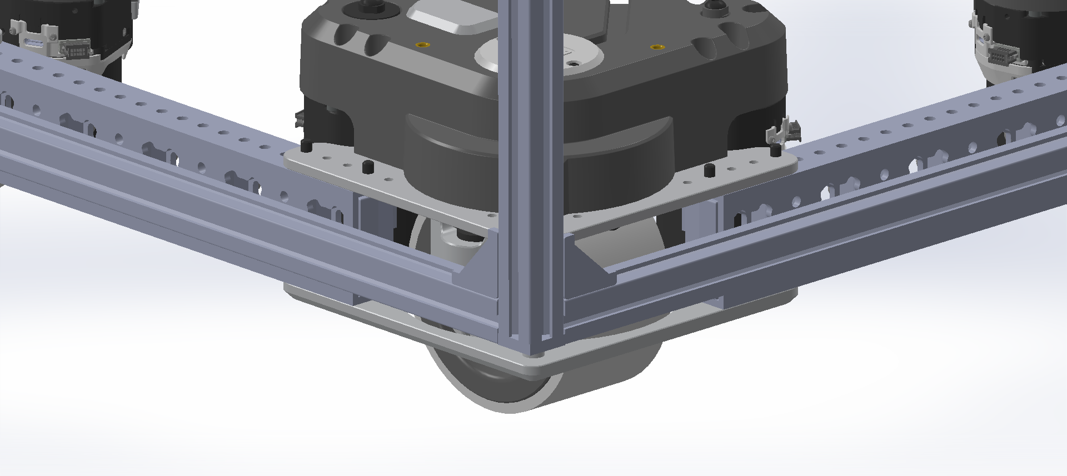
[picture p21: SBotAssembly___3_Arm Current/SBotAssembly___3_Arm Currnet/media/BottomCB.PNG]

\caption{A corner bracket installed at a 90$^\circ$ joint with two T-Nuts
and two button head screws.}
\end{figure}

\assemblystep{Install L-Shape Corner Plates}
Install a L-shape corner plate at each of these locations using 4 T-Nuts
and 4 M5x8mm button head screws. Do not tighten until all 4 screws are
in place. Be sure to secure with Loctite.

\begin{figure}[H]
\centering
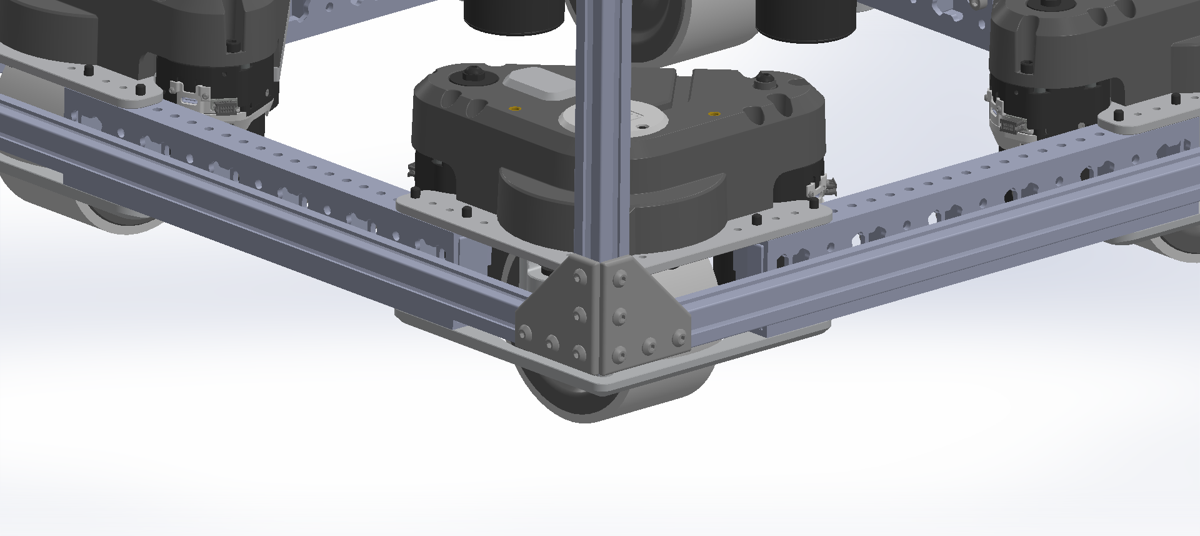
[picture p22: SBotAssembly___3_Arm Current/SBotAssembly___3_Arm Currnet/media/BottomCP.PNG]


\caption{An L-shape corner plate fastened with four T-Nuts and four
button head screws.}
\end{figure}

\assemblystep{Add the Underside Extrusions}
Affix two pieces of 20x20x508 extrusions to the underside of the base
using a T-Nut and a M5x50mm socket head screw on each end. Use the
mounting holes on the inner side of the internal supports of the 2x1"
channels as shown below. Be sure to secure with Loctite.

\begin{figure}[H]
\centering
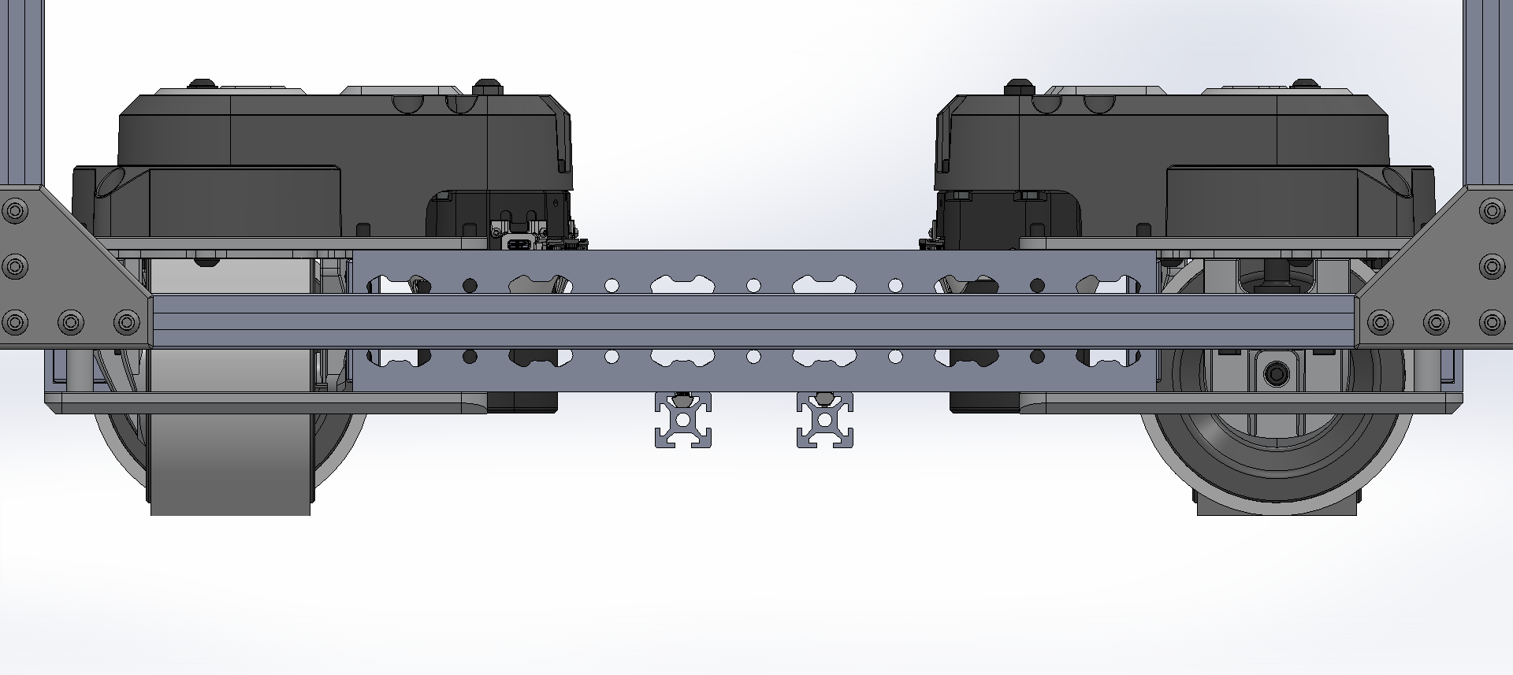
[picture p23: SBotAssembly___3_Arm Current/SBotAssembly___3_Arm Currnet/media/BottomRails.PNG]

\hfill
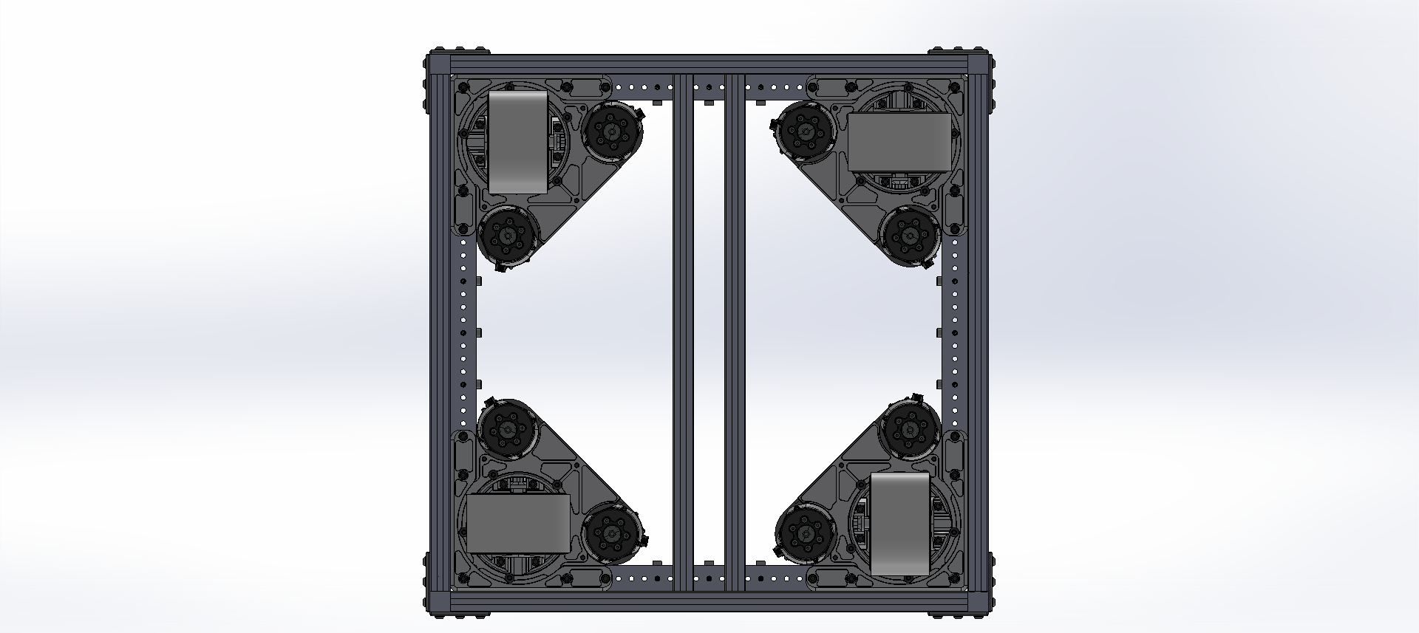
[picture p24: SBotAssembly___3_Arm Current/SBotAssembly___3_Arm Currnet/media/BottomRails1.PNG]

\caption{Two 20x20x508 extrusions affixed to the underside of the base
along the internal supports.}
\end{figure}

\assemblystep{Build the Control Box Mounts}
Cut a piece of 3x1 inch linear rail to 5" and a piece of the 2x1"
channel to 3". Use two M5x16mm bolts, washers, and nuts to secure the
channel to top of the existing channel on one of the sides that the
bottom two 20x20mm extrusions are not mounted to. 
Secure the linear rail to the top of the channel with two M5x10mm bolts, washers, and nuts. Be sure to secure with Loctite.

\begin{figure}[H]
\centering
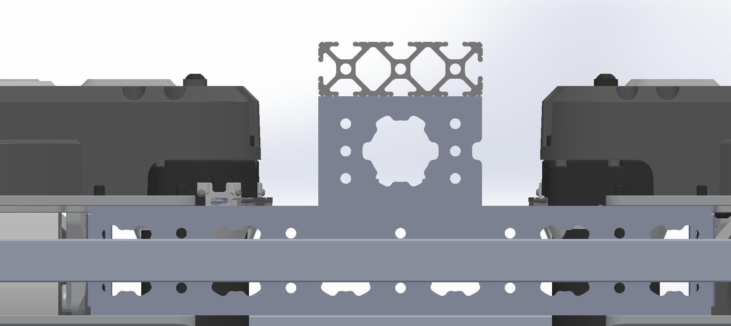
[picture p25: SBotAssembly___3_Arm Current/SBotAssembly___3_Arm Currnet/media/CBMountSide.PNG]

\hfill
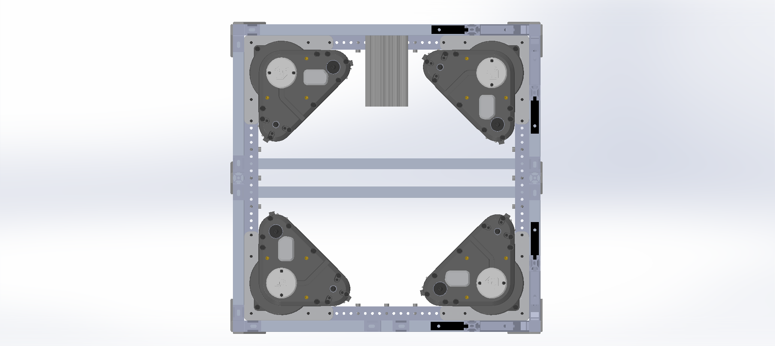
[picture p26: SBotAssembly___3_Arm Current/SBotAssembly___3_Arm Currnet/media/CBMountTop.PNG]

\caption{Control box mount.}
\end{figure}

\assemblystep{Mount the Battery}
Place the Anker battery in the center of the base along the extrusions.
Affix using the ratcheting rope hangers by wrapping the non-ratchet end
around a extrusion and clipping the carabiner to the rope. Feed the
other end around both extrusions, then up to the battery handle. Wrap
around the handle twice before bringing the ratchet down and clipping to
the first carabiner. Pull the excess rope until tight and tie a knot a
few inches away from the ratchet. Cut the excess.

\begin{figure}[H]
\centering
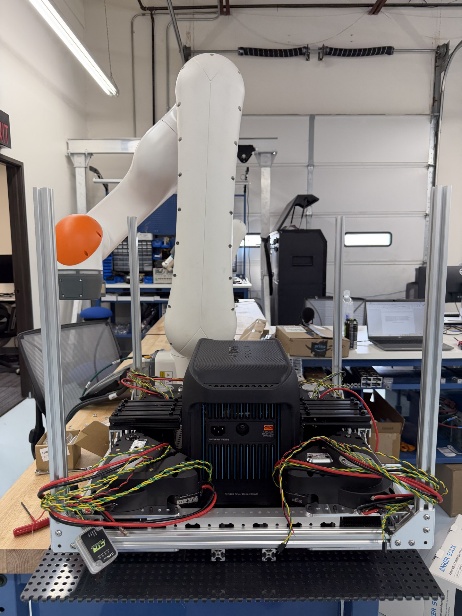
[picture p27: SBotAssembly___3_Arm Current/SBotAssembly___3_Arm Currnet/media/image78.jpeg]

\hfill
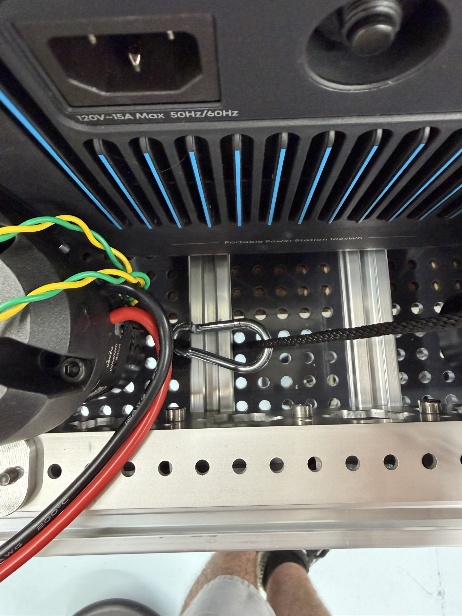
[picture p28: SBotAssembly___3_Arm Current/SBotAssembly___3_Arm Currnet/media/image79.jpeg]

\hfill
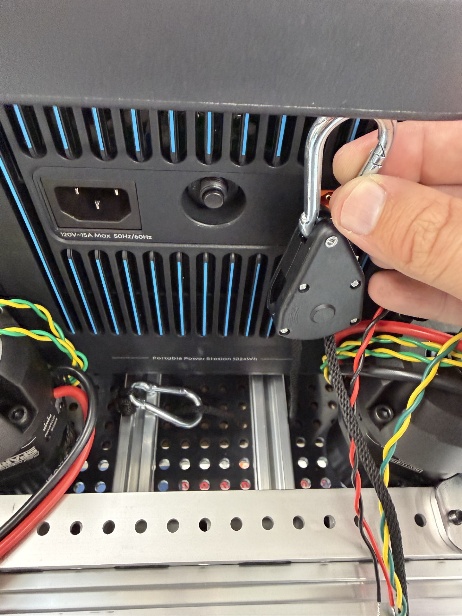
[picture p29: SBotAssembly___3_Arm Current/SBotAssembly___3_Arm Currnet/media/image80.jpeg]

\hfill
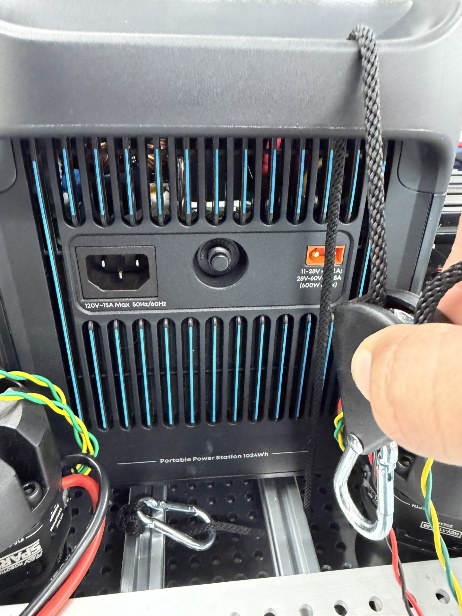
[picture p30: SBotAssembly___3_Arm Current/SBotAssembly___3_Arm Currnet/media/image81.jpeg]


\vspace{0.4cm}
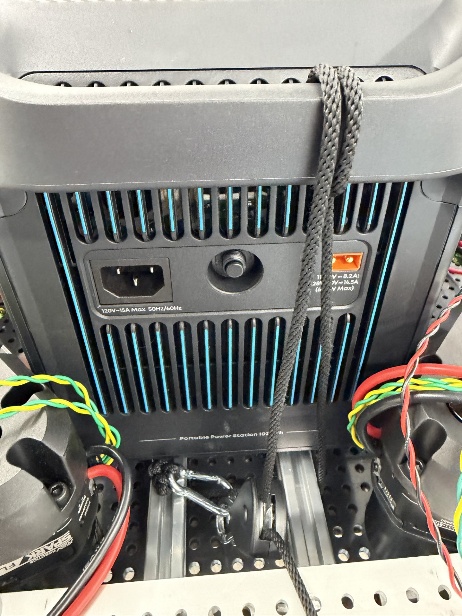
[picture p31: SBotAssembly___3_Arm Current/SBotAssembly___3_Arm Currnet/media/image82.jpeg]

\hfill
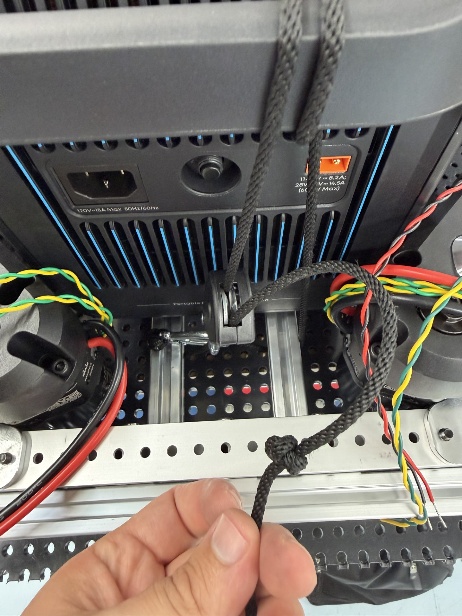
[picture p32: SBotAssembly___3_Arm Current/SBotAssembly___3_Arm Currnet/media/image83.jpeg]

\hfill
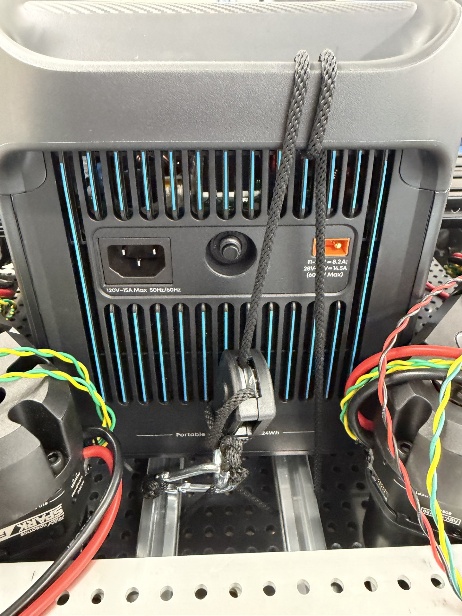
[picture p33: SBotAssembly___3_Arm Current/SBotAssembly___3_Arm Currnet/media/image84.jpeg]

\hfill
\hspace{0.23\textwidth}
\caption{Securing the Anker battery to the base with ratcheting rope
hangers.}
\end{figure}

\assemblystep{Route and Solder the Signal Wires}
Starting with the encoder that has the CANivore, take the other set of
signal wires and daisy-chain them to the next encoder. Repeat until the
4 encoders are in series. Repeat these steps with all motor signal wires
as well. Next, trim the wires to take the slack out and solder them
together. Do not forget to add shrink wrap to prevent shorts in exposed
wires. Leave enough slack for adequate cable management. Use zip ties to
attach to frame. It may be useful to remove the battery, but make sure
cables will not be pulled by battery upon reinstallation.

\begin{figure}[H]
\centering
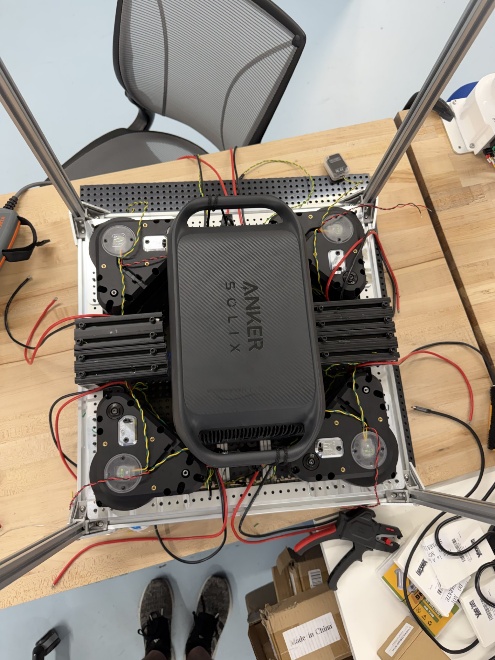
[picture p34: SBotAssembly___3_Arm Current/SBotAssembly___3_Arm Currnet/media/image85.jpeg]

\hfill
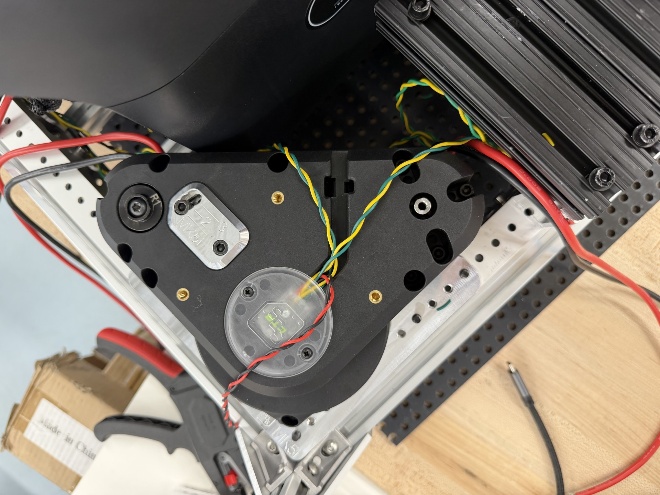
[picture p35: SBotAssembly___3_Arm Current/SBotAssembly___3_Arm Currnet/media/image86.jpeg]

\caption{Daisy-chaining, trimming, and soldering the encoder and motor
signal wires with shrink wrap.}
\end{figure}

\assemblystep{Install the Lower Control Box}
Place the XArm 850 A/C control box on each control box stand. Be sure that the
emergency stop is facing upwards and the power switch is facing the
side designated as the front. The handle may need to be removed from the
unit. Affix with a double-sided adhesive, such as Velcro.

\begin{figure}[H]
\centering
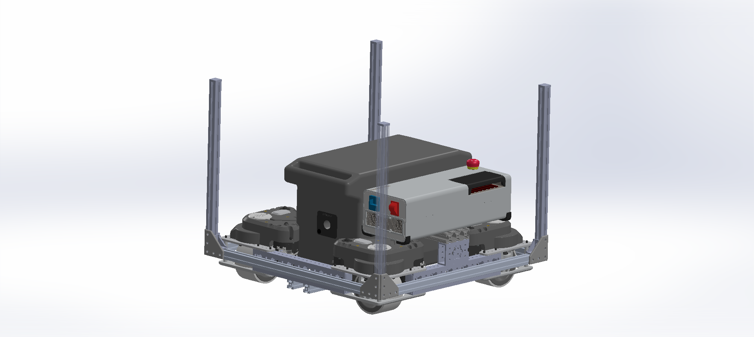
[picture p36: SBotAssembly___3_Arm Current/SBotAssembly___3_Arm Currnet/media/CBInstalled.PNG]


\caption{An A/C control box mounted on its stand with the emergency stop
facing upwards.}
\end{figure}

\assemblystep{Install Vertical Bracing to Middle Layer}
Install 4 20x20x205mm vertically on the center of each side of the horizontal extrusions using 2 corner brackets, 4 T-Nuts, and 4 M5x8mm button head screws on each extrusion. Be sure to secure with Loctite.
Then, install a T-Plate over each joint using 4 T-Nuts and 4 M5x8mm button head screws. Be sure to secure with Loctite.

\begin{figure}[H]
\centering
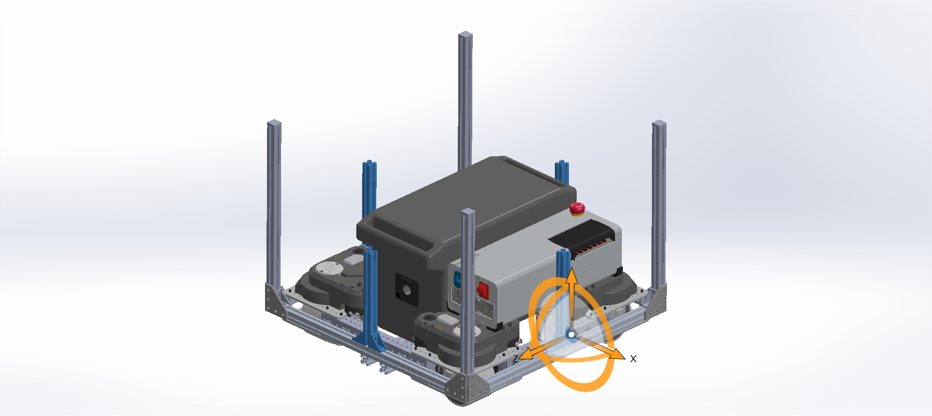
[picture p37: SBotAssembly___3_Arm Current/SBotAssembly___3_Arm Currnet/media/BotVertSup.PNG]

\hfill
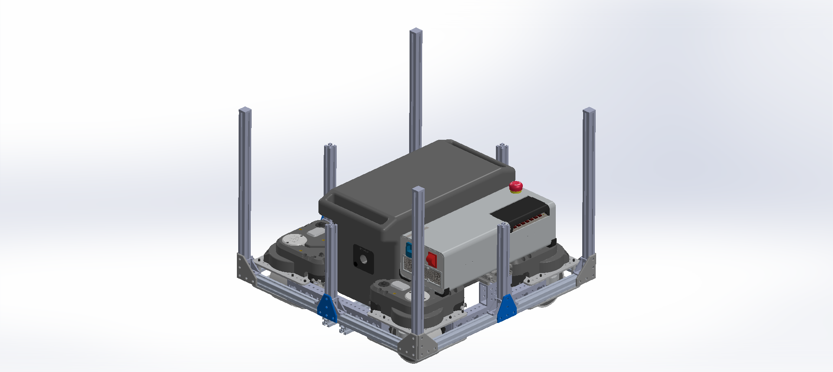
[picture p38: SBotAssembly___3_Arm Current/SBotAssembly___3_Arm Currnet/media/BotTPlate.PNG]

\caption{Vertical bracing and T-plates installed on the center of each
side of the horizontal extrusions.}
\end{figure}

\assemblystep{Install Angled Bracing to Middle Layer}
Install a 135\textdegree angle bracket on each side of the two front corners using a T-Nut and a M5x10mm button head screw. One end should be coincident with the corner bracket.
Install a trapezoidal shaped brace with the longest edge being 164mm above the 135\textdegree angle bracket with another T-Nut and M5x10mm button head screw.
Install a 45\textdegree angle bracket connecting the brace to the vertical extrusion with a T-Nut and M5x10mm button head screw.
Install another 45\textdegree angle bracket with one side aligned with the upward facing side of the brace and extending towards the corner. Use a T-Nut and M5x10mm button head screw.
Be sure to secure with Loctite.

\begin{figure}[H]
  \centering
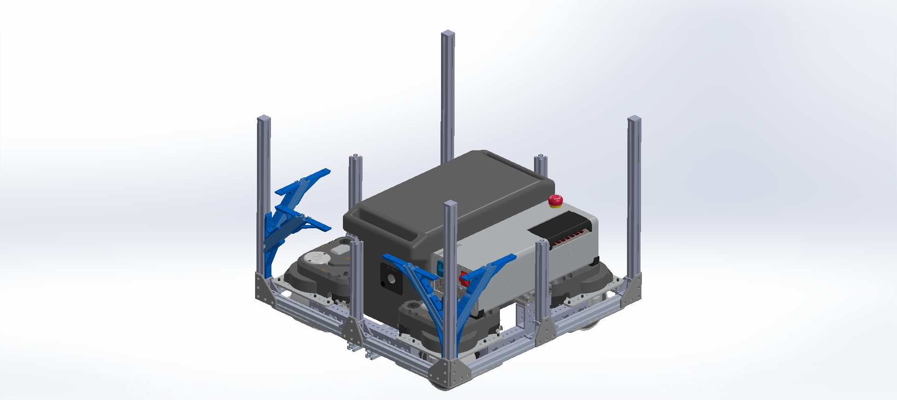
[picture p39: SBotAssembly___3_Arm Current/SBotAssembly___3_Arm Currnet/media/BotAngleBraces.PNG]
  

  \caption{The angled support braces installed.}
\end{figure}

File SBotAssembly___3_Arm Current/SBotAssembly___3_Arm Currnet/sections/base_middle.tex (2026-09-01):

\section{Base Assembly - Middle Level}
\resetassemblysteps

\begin{partsbox}
\begin{minipage}[t]{\linewidth}
\vspace{0pt}
\begin{itemize}
\item
  8
  \href{https://www.amazon.com/2020-Bracket-Aluminum-Extrusion-Connector/dp/B0B15LWB96/ref=sr_1_4?crid=GBX1DKP7GAGY\&dib=eyJ2IjoiMSJ9.YwZZJkrg4tHSDQtAhQFm_xWTziZvc73fSAx6Xu3V0eU9Pqt2kpgHOMdfl-j03eXqLr9SqVJYsOjBRsPwTCeRLPtVxaWp92QOj3YkpEqxe_f8uoBLlCDSbJNoPuO7oEmj38Xk2B-rbRdMmVb4LCTjK_d-28hle0DLks3O0dHpkuvaCBjan9vx2tdJSw9iC-mnxOK3t7UgCEoea3K5irfrMBFTM5oumf1ZcDhywTPPYWw._AcCkrgnzVeJorywdvUhORfM7Ll_8HjaW-XAmTmjHmU\&dib_tag=se\&keywords=10\%2Bpcs\%2B2020\%2Bcorner\%2Bbracket\%2Bjoint\%2Bplate\%2Bbaykailin\&nsdOptOutParam=true\&qid=1780009641\&sprefix=10\%2Bpcs\%2B2020\%2Bcorner\%2Bbraket\%2Bjoint\%2Bplate\%2Bbaykailin\%2Caps\%2C145\&sr=8-4\&th=1}{L
  Shape Corner Plates}
\item
  8
  \href{https://www.amazon.com/32Pcs-Bracket-Aluminum-Extrusion-Industrial/dp/B0C19C1G8W/ref=sr_1_2?crid=2ZFRAXDPV6K9C\&dib=eyJ2IjoiMSJ9.9llDtPZ6rC_p4rDCn1uyFMxeYyRqWBqgLth9R1QRUb9haw9tHsyhizxJVyQVEJX5E5PHdfHeTqni3lrNDXwIjGCy2CiyC60eyHkbztAObX37nNxon_ILhSnd09eTZLvc84vumvQUyfKhNQYpPDhZgRcfddb-_4-e74BTyMMXhbZpMVmt0jbXza8zo7j_JoYYlt-aRjExxcLoMb4P7yTEhUpbAyACgTkJjVQYmn20FDY.kABSI1pFjrAhVJf0W1q_K6ofkuv8qBnGbZljKoPPBOA\&dib_tag=se\&keywords=32\%2Bpcs\%2Bcorner\%2Bbracket\%2B(20x17)\%2B2020\%2BNVAXQF\&qid=1780009800\&sprefix=32\%2Bpcs\%2Bcorner\%2Bbracket\%2B20x17\%2B2020\%2Bnvaxqf\%2Caps\%2C154\&sr=8-2\&th=1}{Corner
  Brackets}
\item
  1 2'x2'x1/4'' Plastic Grid Board
\item
  4 20mmx20mmx510mm Aluminum T-Slot Extrusion
\item
  56
  \href{https://www.amazon.com/100-Pack-Aluminum-Extrusions-Profile-Accessories/dp/B07VHNGBWJ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\&dib=eyJ2IjoiMSJ9.5erSjcFGuqxSi7i2L21rT0vbw0ytuhxrp2ltZMOLJ8UqIwudlyaYHt6ZpRlbWvk8FE864dYDJ1VLjjJk06LhvL07sQfFYWLzdZL2KVXkDSPyUpj40WzXATJ8pfYO-zARlj70J7cKX5n7kSFpZu9gwaq8QH-tRelX3ksKgh7TlIR0J96mfletc1Kltj1N9UXhiUmpMmKqw3YiYb35hBPuc4xUwdT7UsevWwIn2pnDoC0.3xr-5AQMwqWdX2mbf9nYZ-dcUiSk-N2MZR-ugnD5pTw\&dib_tag=se\&keywords=100-pack\%2B2020\%2Broll\%2Bin\%2Bspring\%2Bloaded\%2Bt\%2Bnut\%2Bm5\%2BPOLISI3D\&nsdOptOutParam=true\&qid=1780010876\&sprefix=100-pack\%2B2020\%2Broll\%2Bin\%2Bspring\%2Bloaded\%2Bt\%2Bnut\%2Bm5\%2Bpolisi3d\%2Caps\%2C142\&sr=8-3\&th=1}{Spring
  Loaded M5 T-Nuts}
\item
  48 M5x8mm Button Head Machine Screws
\item
  8 M5x12mm Machine Screws
\end{itemize}
\end{minipage}
\end{partsbox}

\assemblystep{Install the Horizontal Extrusions}
Attach the extrusions horizontally along the perimeter of the base
between the vertical extrusions. Center at 265mm from the top of the
vertical extrusions and affix with corner brackets underneath the
horizontal extrusion. Secure with Loctite.

\begin{tipbox}
Image needed: side view showing the corner brackets and tape measure.
\end{tipbox}

\assemblystep{Cut the Grid Board}
Cut the grid board to 510mmx510mm. Cut a 25mmx25mm square out of each
corner. Cut a [diameter] hole [dist] from one edge and [dist] from it's adjacent edge. Set aside.

\begin{tipbox}
Image needed: the cut grid board.
\end{tipbox}

\assemblystep{Install the Grid Board}
Place 2 T-Nuts on the topside of each horizontal aluminum extrusion. Set
the grid board on top with the [diameter] hole closest to the rear back corner of the Sbot. Secure with M5x12mm bolts and washers.

\begin{tipbox}
The board is in imperial units, so additional holes may need to be
drilled to fully secure it.
\end{tipbox}

\begin{tipbox}
Image needed: the grid board mounted on the base.
\end{tipbox}

\assemblystep{Install the PDP}
Place the PDP (Power Distrubution Panel) in the center of the of the grid board and affix with either velco strips or with M5 socket screws, washers, and nuts. Be sure to have the panel oriented parallel with the front edge of the SBot and that the battery connector is facing the rear.

\begin{tipbox}
Image needed: PDP on gridboard
\end{tipbox}

Each of the motor and encoder power cables should be fed through the grid board to reach the PDP. Extend any cables as necessary with additional wire and WAGO connectors. Crimp each cable end before inserting into the PDP. It is recommended that each set of cables go to the corner of the PDP closest to it's respective Swerve Module.

\begin{tipbox}
    Image needed: PDP wired
\end{tipbox}

\assemblystep{Install the Meta Quest 3S}
Install the bottom half of the Quest mount to the front of the SBot using M5 socket screws.

\begin{tipbox}
    Image needed: Bottom half of the quest mount
\end{tipbox}

Tie the elastic cord in a loop and place into the groove on the bottom half of the mount before placing the top half on top. Secure with M5 socket screws. Press the Quest onto the front of the mount and pull the cord over the front and around the hook on top.

\begin{tipbox}
    Image needed: 2 images, assembled mount and then with quest on it
\end{tipbox}

\assemblystep{Install Quest Adapter}
Secure the Quest adapter with velcro adhesive strips behind the Quest. Plug the USB-C cable into the quest.

\begin{tipbox}
    Image needed: quest adapter
\end{tipbox}

\assemblystep{Install the PC}
Place the PC in the front right corner of the gridboard. The rear should be facing the back of the SBot. Secure with velcro straps. The feet may need to be removed for proper adhesion. 

\begin{tipbox}
    Image needed: pc installed
\end{tipbox}

\assemblystep{Install Battery}
Secure the battery in the rear left corner of the SBot with vecro strips. Be sure that the battery connector can easily reach the other end that is attached to the PDP. Secure the breaker switch the the grip board using a M5 socket screw, washers, and nuts.

\begin{tipbox}
    Image Needed: battery installed and connected.
\end{tipbox}

\assemblystep{Connect CANs}
Place the CAN USB and the CANivore on the front left corner of the SBot, and feed the wires through the gridboard. Secure with velcro adhesive strips. Connect a USB to USB-C cable to the CANivore. Connect both modules to a USB expansion hub and afiix with velcro. Connect the other end of the hub to a rear USB port on the PC.

\begin{tipbox}
    Images needed: CANs and hub, back of PC
\end{tipbox}

\assemblystep{Install the Ethernet Switch}
Affix the ethernet switch anywhere in the rear right corner. Connect a short ethernet cable between the PC and the swith. Connect a longer cable from the switch to Quest adapter and from the switch to the control box.

\begin{tipbox}
    Images needed: switch with rear of pc, quest switch, arm control box
\end{tipbox}

\assemblystep{Connect Power Cables}
Connect power cables from the power supply to the control box and the PC. If needed, the two screws can be removed and the connector on the PC can be fliiped the other way around. Connect a USB to USB-C cable to the ethernet switch and the dual USB-C adapter plugged into the power supply. Connect a USB-C cable from the Quest adapter and the dual USB-C adapter. 

\begin{tipbox}
    Images needed: photos showing all power cables
\end{tipbox}

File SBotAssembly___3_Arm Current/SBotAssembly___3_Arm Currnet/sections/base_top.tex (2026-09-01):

\section{Base Assembly - Top Level}
\resetassemblysteps

\begin{partsbox}
\begin{minipage}[t]{\linewidth}
\vspace{0pt}
\begin{itemize}

\item
  4 items
\item
    %item2
    
\end{itemize}
\end{minipage}
\end{partsbox}

\assemblystep{Assemble Top Frame}
Connect 4 pieces of the 2020 x 510mm aluminum extrusions using the three directional connectors and fasten with set screws. Place two parallel extrusions [dist] apart and centered in the frame. Use corner brackets, T-Nuts, and M5x10mm buttonhead screws to secure to the frame.

\begin{tipbox}
    Image needed: square frame
\end{tipbox}

\assemblystep{Install and Secure Top Frame}
Place the top frame on top of the SBot, making sure to align the prongs of the three directional connectors with the vertical extrusions. Secure with the provided set screws. Install corner brackets at all 8 corners made by the top frame and the sides. Install a corner plate over each corner bracket.

\begin{tipbox}
    Images needed: frame on bot, corner brackets installed, plates installed
\end{tipbox}

\assemblystep{Install Bracing}
Install two 2020 extrusion braces in the front and two in the back. The braces will be trapezoidal in shape with one side being [length] long and the other being [length] long. The angle is 45 degrees on both sides. Secure with two 45 degree brackets and 1 135 degree bracket and T-Nuts for each brace.

\begin{tipbox}
    Images needed: simple drawing of brace, braces on front, on back
\end{tipbox}

\assemblystep{Install the Arm}
Align the short edge of the mounting plate with the front edge of the SBot and the long edges with the two extrusions on the top. Secure with T-Nuts and M5x[length] socket screws. Place the arm on top facing the front and secure using the provided screws.

\begin{tipbox}
    Images needed: plate attached, arm attached
\end{tipbox}

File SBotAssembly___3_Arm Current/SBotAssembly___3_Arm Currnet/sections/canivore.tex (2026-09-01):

\section{Encoder and CANivore Set Up and Motor Testing}
\resetassemblysteps

\begin{partsbox}
\begin{minipage}[t]{\linewidth}
\vspace{0pt}
\begin{itemize}
\item
  PDP and Swerve Module Assembly set up
\item
  \href{https://store.ctr-electronics.com/products/canivore?_pos=1\&_psq=CANiv\&_ss=e\&_v=1.0}{CANivore
  Bus Expansion} --
  \href{https://ctre.download/files/user-manual/CANivore\%20User's\%20Guide.pdf}{User
  Guide} --
  \href{https://github.com/CrossTheRoadElec/Device-CADs/raw/master/CANIVORE_CAD/CANivore.zip}{CAD/Drawings}
\end{itemize}
\end{minipage}
\end{partsbox}

\assemblystep{Connect the First Encoder to the CANivore}
Press the red button on the 120A circuit breaker to turn off the
circuit. You will see the yellow lever rotate out if it is not already.
Take one pair of the green and yellow signal wires from one of the
encoders and either remove the jumper connector or trim and strip the
wires. While pressing the tan button on the CANivore unit, insert the
cables into the correctly labeled slot.

\begin{figure}[H]
\centering
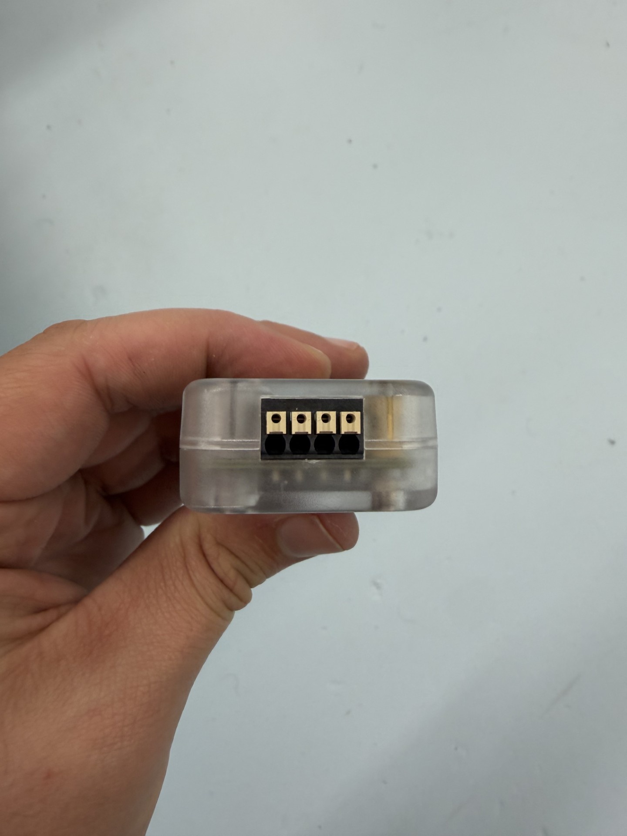
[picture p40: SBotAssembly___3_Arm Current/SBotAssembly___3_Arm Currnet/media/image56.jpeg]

\hfill
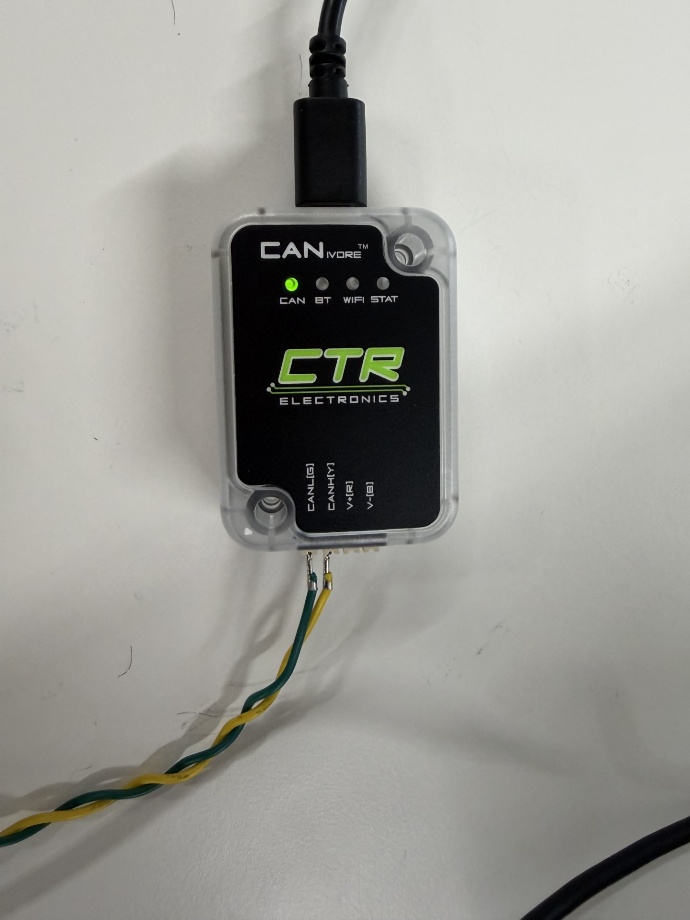
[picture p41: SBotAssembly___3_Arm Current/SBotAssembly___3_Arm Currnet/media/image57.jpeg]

\caption{Inserting the encoder signal wires into the labeled CANivore
slot while pressing the tan button.}
\end{figure}

\assemblystep{Link the Encoders in Series}
Connect the other set of jumper connectors for the same encoder to the
corresponding connectors on the next encoder. Repeat so all 4 encoders
are linked in series.

\begin{figure}[H]
\centering
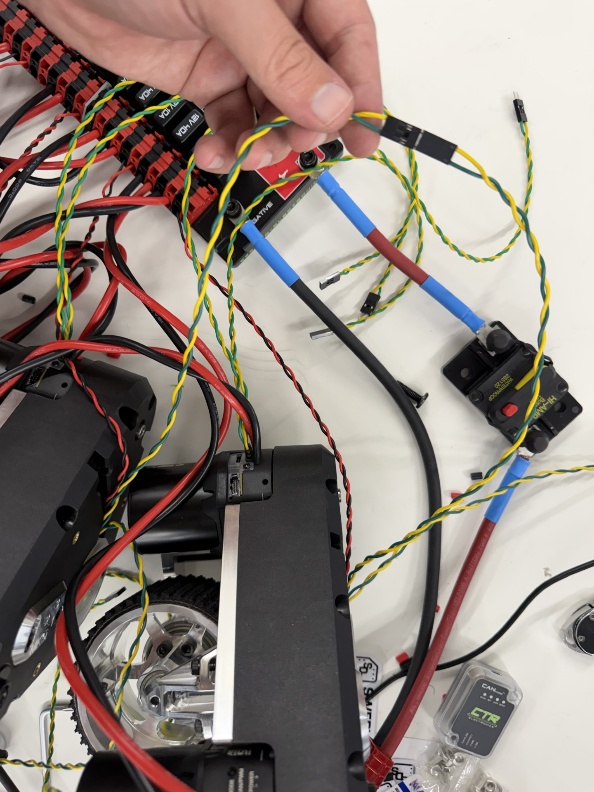
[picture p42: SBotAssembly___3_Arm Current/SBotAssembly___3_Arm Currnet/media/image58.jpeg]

\caption{Jumper connectors linking one encoder to the next, in series.}
\end{figure}

\assemblystep{Configure the CANivore}
Connect the CANivore to a computer via USB-C and launch the Phoenix
Tuner X app. Navigate to the CANivores tab and select the now visible
``Default Name'' item. Here you can rename the device and update the
firmware.

\begin{figure}[H]
\centering
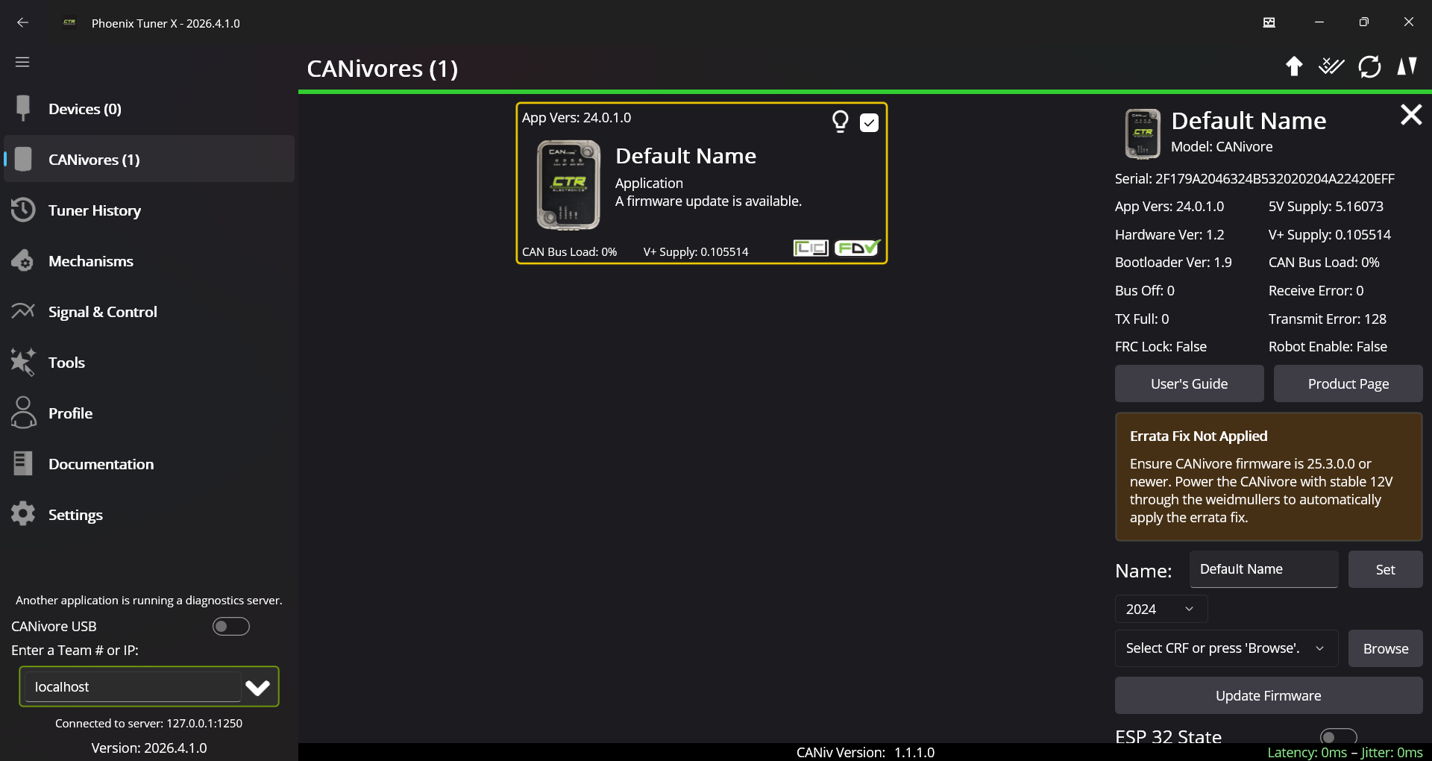
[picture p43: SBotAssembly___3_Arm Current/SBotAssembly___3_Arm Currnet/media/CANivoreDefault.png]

\caption{The CANivore shown under the CANivores tab in Phoenix Tuner~X.}
\end{figure}

\assemblystep{Configure the Encoders}
After updating, an item will be visible in the devices tab. This item
will show that there are 4 devices with this device. When clicked, the
first encoder will appear. Rename the device ID and update the firmware.
In this case, 1-4 was used for the device IDs. Repeat for all encoders
connected to the CANivore.

\begin{figure}[H]
\centering
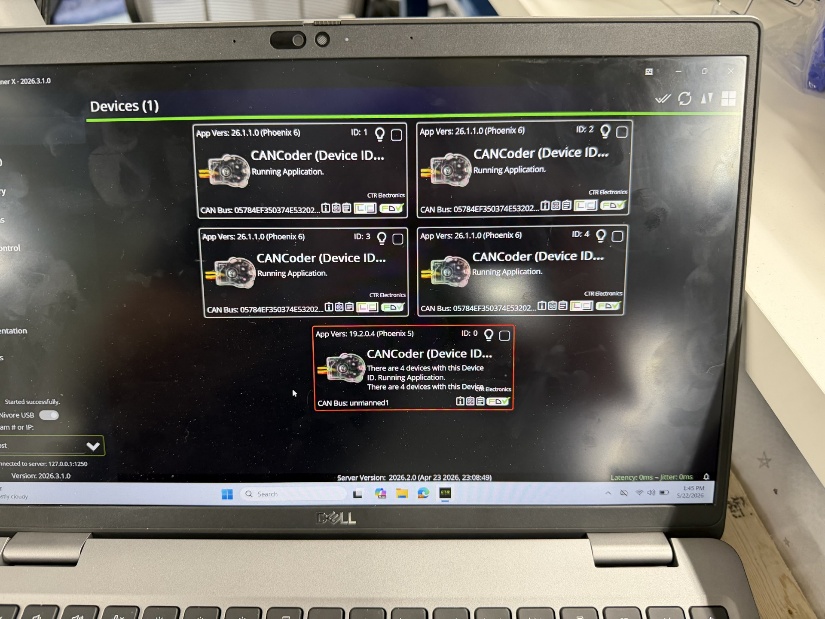
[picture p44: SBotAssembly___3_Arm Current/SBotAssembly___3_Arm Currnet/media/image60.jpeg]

\hfill
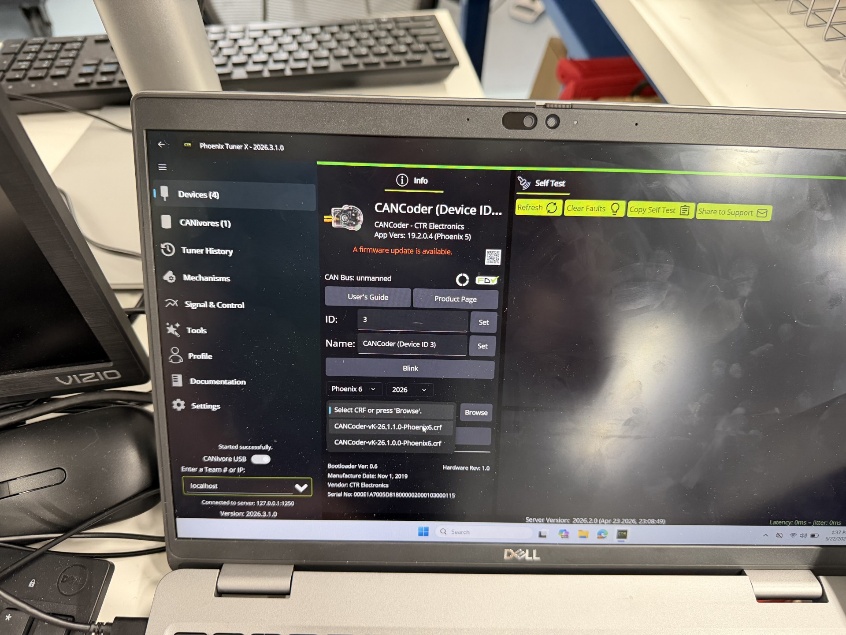
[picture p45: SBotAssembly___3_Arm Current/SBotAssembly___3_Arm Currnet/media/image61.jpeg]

\caption{Renaming each encoder's device ID and updating its firmware in
the devices tab.}
\end{figure}

\assemblystep{Test the Motors}
\begin{figure}[H]
\centering
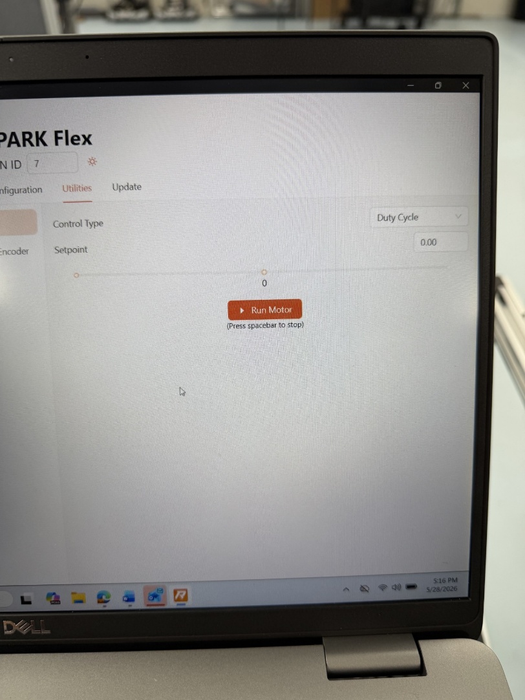
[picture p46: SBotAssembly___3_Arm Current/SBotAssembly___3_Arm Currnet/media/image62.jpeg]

\caption{Running a motor from the Utilities tab to verify drive and steer
movement.}
\end{figure}

Press the yellow lever in to power on the motors. Connect to a motor in
the REV Hardware Client 2 via USB-C. Prop the motor up so that the wheel
is not touching the ground and is clear to turn and rotate. Under the
Utilities tab for the motor, click run motor then change the set point
slightly in both the positive and negative directions. Drive motors
should spin the wheel while steer motors should change the direction.

\begin{tipbox}
Values between .25 and .5 are enough to make the motors spin. Too high
of a set point will make the motor spin rapidly.
\end{tipbox}

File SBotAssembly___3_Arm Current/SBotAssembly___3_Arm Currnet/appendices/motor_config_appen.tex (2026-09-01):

\section{Motor Controller Configurations}
\pagestyle{fancy}
\fancyhf{}
\lhead{S-Bot Assembly Guide}
\rhead{APPENDICES - APPENDIX A}
\label{app:motor-config}
This appendix contains the conplete SPARK Flex configurations

\rowcolors{2}{gray!10}{white}
\begin{longtable}{p{3.5cm} p{8cm} p{3cm}}

\toprule
\rowcolor{sbotblue!15}
\textbf{Tab} & \textbf{Setting} & \textbf{Value} \\
\midrule
\endfirsthead

\toprule
\rowcolor{sbotblue!15}
\textbf{Tab} & \textbf{Setting} & \textbf{Value} \\
\midrule
\endhead

\bottomrule
\endfoot

Basic & Motor Type & \texttt{Brushless} \\
Basic & Idle Mode & \texttt{BRAKE} \\
Basic & Input Deadband & \texttt{0.05} \\
Basic & Inverted & \texttt{Off} \\
Basic & Open Loop Ramp Rate & \texttt{0} \\

Motor Advanced & Commutation Advance & \texttt{0} \\
Motor Advanced & Motor Kv & \texttt{480} \\

Brushless & Pole Pairs & \texttt{7} \\

Current Limits & Current Chop & \texttt{115} \\
Current Limits & Current Chop Cycles & \texttt{0} \\
Current Limits & Smart Current Stall Limit & \texttt{80} \\
Current Limits & Smart Current Free Limit & \texttt{20} \\

Closed Loop Control & Closed Loop Control Sensor & \texttt{MAIN\_ENCODER} \\
Closed Loop Control & Voltage Compensation Mode & \texttt{NO\_VOLTAGE\_COMP} \\
Closed Loop Control & Compensated Nominal Voltage & \texttt{0} \\
Closed Loop Control & Closed Loop Ramp Rate & \texttt{0} \\
Closed Loop Control & Position PID Wrap Enable & \texttt{OFF} \\
Closed Loop Control & Position PID Min Input & \texttt{0} \\
Closed Loop Control & Position PID Max Input & \texttt{0} \\
Closed Loop Control & Detached Encoder Device ID & \texttt{Leave Blank} \\

Closed Loop Control Slot 0 & P0 & \texttt{Steer Motor: 0.5, Drive Motor: .119} \\
Closed Loop Control Slot 0 & I0 & \texttt{0} \\
Closed Loop Control Slot 0 & D0 & \texttt{0} \\
Closed Loop Control Slot 0 & V0 & \texttt{0} \\
Closed Loop Control Slot 0 & IZone 0 & \texttt{0} \\
Closed Loop Control Slot 0 & D Filler 0 & \texttt{0} \\
Closed Loop Control Slot 0 & Output Min 0 & \texttt{-1} \\
Closed Loop Control Slot 0 & Output Max 0 & \texttt{1} \\
Closed Loop Control Slot 0 & I Max Accum 0 & \texttt{0} \\
Closed Loop Control Slot 0 & Allowed Closed Loop Error 0 & \texttt{0} \\
Closed Loop Control Slot 0 & MAXMotion Cruise Velocity 0 & \texttt{0} \\
Closed Loop Control Slot 0 & MAXMotion Max Accek 0 & \texttt{0} \\
Closed Loop Control Slot 0 & MAXMOtion Max Jerk 0 & \texttt{0} \\
Closed Loop Control Slot 0 & MAXMotion Allowed Profile Error 0 & \texttt{0} \\
Closed Loop Control Slot 0 & MAXMotion Position Mode 0 & \texttt{Trapezoidal} \\
Closed Loop Control Slot 0 & S0 & \texttt{0} \\
Closed Loop Control Slot 0 & A0 & \texttt{0} \\
Closed Loop Control Slot 0 & G0 & \texttt{0} \\
Closed Loop Control Slot 0 & Cos 0 & \texttt{0} \\
Closed Loop Control Slot 0 & CosRatio 0 & \texttt{1} \\

Closed Loop Control Slot 1 & P1 & \texttt{0} \\
Closed Loop Control Slot 1 & I1 & \texttt{0} \\
Closed Loop Control Slot 1 & D1 & \texttt{0} \\
Closed Loop Control Slot 1 & V1 & \texttt{0} \\
Closed Loop Control Slot 1 & IZone 1 & \texttt{0} \\
Closed Loop Control Slot 1 & D Filter 1 & \texttt{0} \\
Closed Loop Control Slot 1 & Output Min 1 & \texttt{-1} \\
Closed Loop Control Slot 1 & Output Max 1 & \texttt{1} \\
Closed Loop Control Slot 1 & I Max Accum 1 & \texttt{0} \\
Closed Loop Control Slot 1 & Allowed Closed Loop Error 1 & \texttt{0} \\
Closed Loop Control Slot 1 & MAXMotion Cruise Velocity 1 & \texttt{0} \\
Closed Loop Control Slot 1 & MAXMotion Max Accek 1 & \texttt{0} \\
Closed Loop Control Slot 1 & MAXMOtion Max Jerk 1 & \texttt{0} \\
Closed Loop Control Slot 1 & MAXMotion Allowed Profile Error 1 & \texttt{0} \\
Closed Loop Control Slot 1 & MAXMotion Position Mode 1 & \texttt{Trapezoidal} \\
Closed Loop Control Slot 1 & S1 & \texttt{0} \\
Closed Loop Control Slot 1 & A1 & \texttt{0} \\
Closed Loop Control Slot 1 & G1 & \texttt{0} \\
Closed Loop Control Slot 1 & Cos 1 & \texttt{0} \\
Closed Loop Control Slot 1 & CosRatio 1 & \texttt{1} \\

Closed Loop Control Slot 2 & P2 & \texttt{0} \\
Closed Loop Control Slot 2 & I2 & \texttt{0} \\
Closed Loop Control Slot 2 & D2 & \texttt{0} \\
Closed Loop Control Slot 2 & V2 & \texttt{0} \\
Closed Loop Control Slot 2 & IZone 2 & \texttt{0} \\
Closed Loop Control Slot 2 & D Filter 2 & \texttt{0} \\
Closed Loop Control Slot 2 & Output Min 2 & \texttt{-1} \\
Closed Loop Control Slot 2 & Output Max 2 & \texttt{1} \\
Closed Loop Control Slot 2 & I Max Accum 2 & \texttt{0} \\
Closed Loop Control Slot 2 & Allowed Closed Loop Error 2 & \texttt{0} \\
Closed Loop Control Slot 2 & MAXMotion Cruise Velocity 2 & \texttt{0} \\
Closed Loop Control Slot 2 & MAXMotion Max Accek 2 & \texttt{0} \\
Closed Loop Control Slot 2 & MAXMOtion Max Jerk 2 & \texttt{0} \\
Closed Loop Control Slot 2 & MAXMotion Allowed Profile Error 2 & \texttt{0} \\
Closed Loop Control Slot 2 & MAXMotion Position Mode 2 & \texttt{Trapezoidal} \\
Closed Loop Control Slot 2 & S2 & \texttt{0} \\
Closed Loop Control Slot 2 & A2 & \texttt{0} \\
Closed Loop Control Slot 2 & G2 & \texttt{0} \\
Closed Loop Control Slot 2 & Cos 2 & \texttt{0} \\
Closed Loop Control Slot 2 & CosRatio 2 & \texttt{1} \\

Closed Loop Control Slot 3 & P3 & \texttt{0} \\
Closed Loop Control Slot 3 & I3 & \texttt{0} \\
Closed Loop Control Slot 3 & D3 & \texttt{0} \\
Closed Loop Control Slot 3 & V3 & \texttt{0} \\
Closed Loop Control Slot 3 & IZone 3 & \texttt{0} \\
Closed Loop Control Slot 3 & D Filter 3 & \texttt{0} \\
Closed Loop Control Slot 3 & Output Min 3 & \texttt{-1} \\
Closed Loop Control Slot 3 & Output Max 3 & \texttt{1} \\
Closed Loop Control Slot 3 & I Max Accum 3 & \texttt{0} \\
Closed Loop Control Slot 3 & Allowed Closed Loop Error 3 & \texttt{0} \\
Closed Loop Control Slot 3 & MAXMotion Cruise Velocity 3 & \texttt{0} \\
Closed Loop Control Slot 3 & MAXMotion Max Accek 3 & \texttt{0} \\
Closed Loop Control Slot 3 & MAXMOtion Max Jerk 3 & \texttt{0} \\
Closed Loop Control Slot 3 & MAXMotion Allowed Profile Error 3 & \texttt{0} \\
Closed Loop Control Slot 3 & MAXMotion Position Mode 3 & \texttt{Trapezoidal} \\
Closed Loop Control Slot 3 & S3 & \texttt{0} \\
Closed Loop Control Slot 3 & A3 & \texttt{0} \\
Closed Loop Control Slot 3 & G3 & \texttt{0} \\
Closed Loop Control Slot 3 & Cos 3 & \texttt{0} \\
Closed Loop Control Slot 3 & CosRatio 3 & \texttt{1} \\

Limits & Limit Switch Fwd Polarity & \texttt{Off} \\
Limits & Limit Switch Rev Polarity & \texttt{Off} \\
Limits & Hard Limit Fwd En & \texttt{STOP\_MOVING\_} \\
Limits & Hard Limit Rev En & \texttt{STOP\_MOVING\_} \\
Limits & Soft Limit Fwd En & \texttt{Off} \\
Limits & Soft Limit Rev En & \texttt{Off} \\
Limits & Soft Limit Forward & \texttt{0} \\
Limits & Soft Limit Reverse & \texttt{0} \\
Limits & Limit Switch Position Sensor & \texttt{NONE} \\
Limits & Limit Switch Fwd Position & \texttt{0} \\
Limits & Limit Switch Rev Position & \texttt{0} \\

Follower Mode & Follower Mode Leader Id & \texttt{0} \\
Follower Mode & Follower Mode Is Inverted & \texttt{OFF} \\

Primary Encoder & Encoder Counts Per Rev & \texttt{409} \\
Primary Encoder & Encoder Average Depth & \texttt{64} \\
Primary Encoder & Encoder Sample Delta & \texttt{200} \\
Primary Encoder & Encoder Inverted & \texttt{OFF} \\
Primary Encoder & Position Conversion Factor & \texttt{1} \\
Primary Encoder & Velocity Conversion Factor & \texttt{1} \\
Primary Encoder & Uvw Sensor Sample Rate & \texttt{0.03125} \\
Primary Encoder & Uvw Sensor Average Depth & \texttt{3} \\

Alternate Encoder & Compatibility Port Config & \texttt{DEFAULT} \\
Alternate Encoder & Alt Encoder Counts Per Rev & \texttt{409} \\
Alternate Encoder & Alt Encoder Average Depth & \texttt{64} \\
Alternate Encoder & Alt Encoder Sample Depth & \texttt{200} \\
Alternate Encoder & Alt Encoder Inverted & \texttt{OFF} \\
Alternate Encoder & Alt Encoder Position Conversion & \texttt{1} \\
Alternate Encoder & Alt Encoder Velocity Conversion & \texttt{1} \\

Duty Cycle Absolute Encoder & Duty Cycle Position Factor & \texttt{1} \\
Duty Cycle Absolute Encoder & Duty Cycle Velocity Factor & \texttt{1} \\
Duty Cycle Absolute Encoder & Duty Cycle Inverted & \texttt{OFF} \\
Duty Cycle Absolute Encoder & Duty Cycle Sensor Mode & \texttt{Absolute} \\
Duty Cycle Absolute Encoder & Duty Cycle Average Depth & \texttt{7} \\
Duty Cycle Absolute Encoder & Duty Cycle Zero Centered & \texttt{Off} \\
Duty Cycle Absolute Encoder & Duty Cycle Sensor Prescaler & \texttt{7} \\
Duty Cycle Absolute Encoder & Duty Cycle Offset & \texttt{0} \\
Duty Cycle Absolute Encoder & Duty Cycle Encoder Start Pulse Us & \texttt{0} \\
Duty Cycle Absolute Encoder & Duty Cycle Encoder End Pulse Us & \texttt{0} \\

Analog Sensor & Analog Position Conversion & \texttt{1} \\
Analog Sensor & Analog Velocity Conversion & \texttt{1} \\
Analog Sensor & Analog Average Depth & \texttt{64} \\
Analog Sensor & Analog Sensor Mode & \texttt{ABSOLUTE} \\
Analog Sensor & Analog Inverted & \texttt{Off} \\
Analog Sensor & Analog Sample Delta & \texttt{200} \\

Status Frame Period & Status 0 Period & \texttt{10} \\
Status Frame Period & Status 1 Period & \texttt{20} \\
Status Frame Period & Status 2 Period & \texttt{20} \\
Status Frame Period & Status 3 Period & \texttt{50} \\
Status Frame Period & Status 4 Period & \texttt{20} \\
Status Frame Period & Status 5 Period & \texttt{200} \\
Status Frame Period & Status 6 Period & \texttt{200} \\
Status Frame Period & Status 7 Period & \texttt{250} \\
Status Frame Period & Status 8 Period & \texttt{20} \\
Status Frame Period & Status 9 Period & \texttt{100} \\

Status Frame Force Enable & Force Enable Status 0 & \texttt{Off} \\
Status Frame Force Enable & Force Enable Status 1 & \texttt{Off} \\
Status Frame Force Enable & Force Enable Status 2 & \texttt{Off} \\
Status Frame Force Enable & Force Enable Status 3 & \texttt{Off} \\
Status Frame Force Enable & Force Enable Status 4 & \texttt{Off} \\
Status Frame Force Enable & Force Enable Status 5 & \texttt{Off} \\
Status Frame Force Enable & Force Enable Status 6 & \texttt{Off} \\
Status Frame Force Enable & Force Enable Status 7 & \texttt{Off} \\
Status Frame Force Enable & Force Enable Status 8 & \texttt{Off} \\
Status Frame Force Enable & Force Enable Status 9 & \texttt{Off} \\

\bottomrule
\end{longtable}

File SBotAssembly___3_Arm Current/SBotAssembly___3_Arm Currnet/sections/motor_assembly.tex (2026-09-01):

\section{Motor Assembly}
\label{sec:motor-assembly}
\resetassemblysteps

%\includegraphics[width=2in,height=1.94723in]{media/image1.jpg}

\begin{partsbox}
\begin{tabularx}{\linewidth}{@{}X m{0.28\linewidth}@{}}
\begin{minipage}[t]{\linewidth}
\vspace{0pt}
\begin{itemize}
    \item 8 \href{https://www.revrobotics.com/rev-21-1652/}{NEO Vortex Brushless Motors}
    \item 8 \href{https://www.revrobotics.com/rev-11-2159/}{SPARK Flex Motor Controllers}
    \item 8 \href{https://www.revrobotics.com/rev-21-2807/}{Vortex Shafts -- 8mm}
\end{itemize}
\end{minipage}
&
\begin{minipage}[t]{\linewidth}
\vspace{0pt}
\centering
\includegraphics[
    width=\linewidth,
    trim=1.2cm 1.2cm 1.2cm 3.5cm,
    clip
]{media/image1.jpg}
\end{minipage}
\end{tabularx}
\end{partsbox}

This section describes how to assemble the NEO Vortex motor with the SPARK Flex motor controller and install the output shaft prior to mounting the assembly to the swerve module.
\clearpage
\assemblystep{Install the Motor Controller}
Align the three circular pins and the rectangular connector on the motor
and controller and firmly press together.

\begin{figure}[H]
\centering
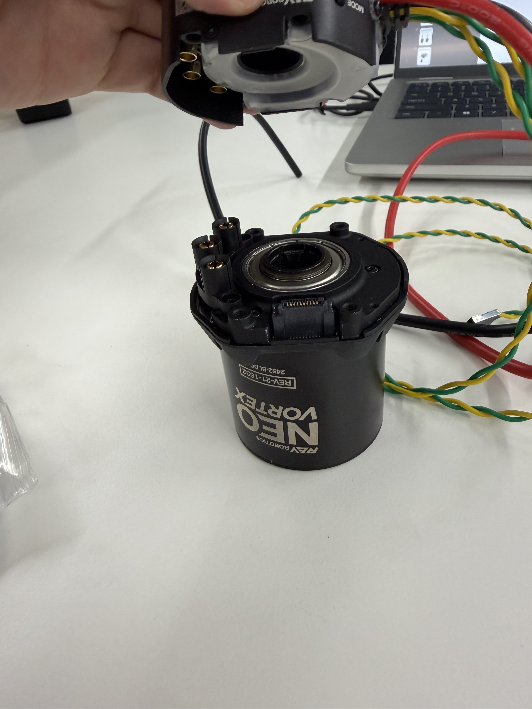
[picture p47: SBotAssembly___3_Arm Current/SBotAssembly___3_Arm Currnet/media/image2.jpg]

\hfill
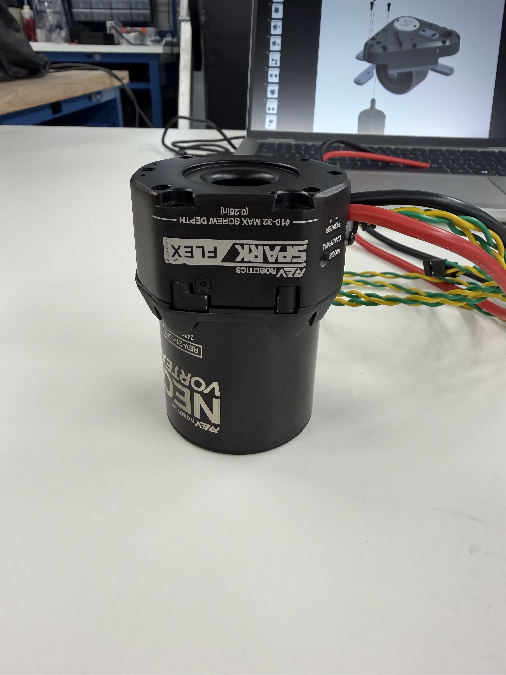
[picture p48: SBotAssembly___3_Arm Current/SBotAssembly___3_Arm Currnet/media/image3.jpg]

\caption{Aligning the pins and connector, then pressing the controller
onto the motor body.}
\end{figure}

\assemblystep{Secure the Controller}
Insert the 4 provided screws into the inset holes on top of the controller (text pointing downwards) to firmly attach the
controller.
\begin{warningbox}
Do not overtighten the controller screws.
\end{warningbox}
%\includegraphics[width=2in,height=1.93557in]{media/image4.jpg}
\clearpage
\assemblystep{Install the Shaft}
With the controller on top, insert the motor shaft into the center of
the motor. The side with the groove along the shaft should be facing
upwards. Then use the provided screw to secure the shaft from the
opposite side of the motor.

\begin{figure}[H]
\centering
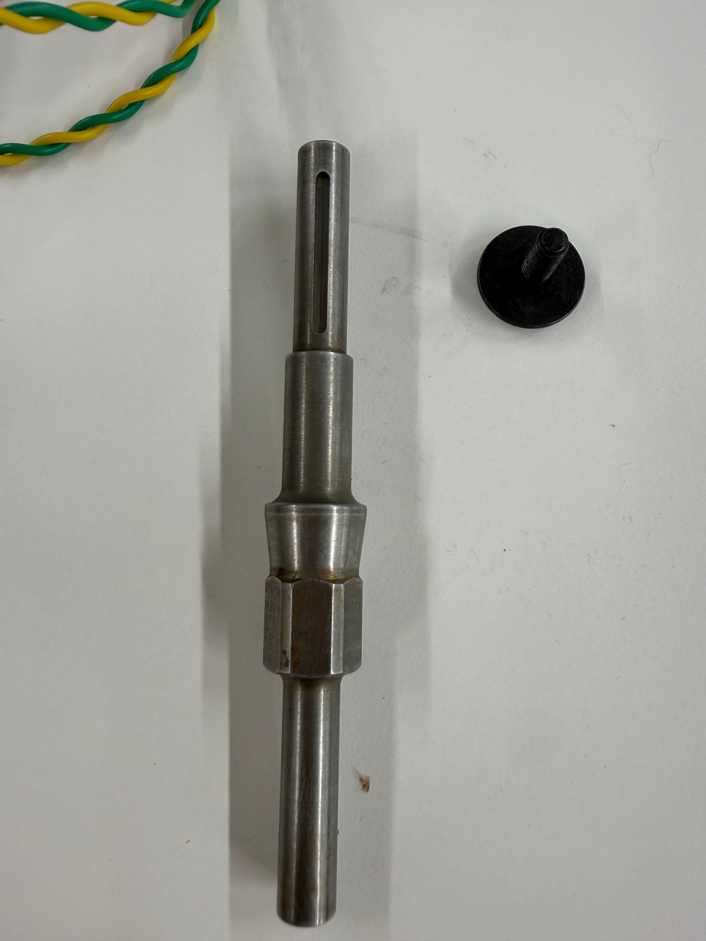
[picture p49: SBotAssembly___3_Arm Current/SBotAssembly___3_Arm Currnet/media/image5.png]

\hfill
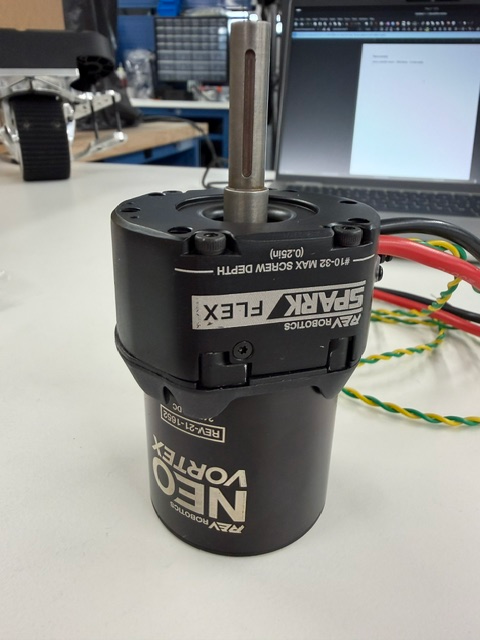
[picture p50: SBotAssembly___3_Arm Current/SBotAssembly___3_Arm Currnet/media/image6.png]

\hfill
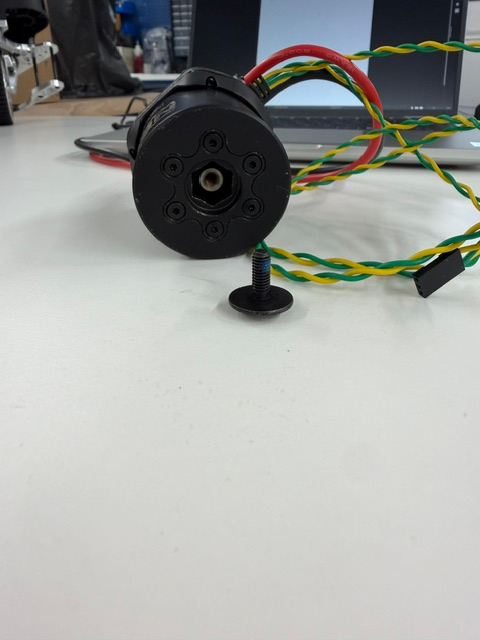
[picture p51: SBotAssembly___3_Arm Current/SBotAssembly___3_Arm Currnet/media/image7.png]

\caption{Inserting the output shaft groove-up and securing it from the
opposite side of the motor.}
\end{figure}

\assemblystep{Assemble Remaining Motors}
Repeat the Motor Assembly steps seven more times to have 8 motors total.

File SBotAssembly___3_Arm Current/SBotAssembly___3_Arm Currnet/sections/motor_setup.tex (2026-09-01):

\section{Motor Set Up}
\resetassemblysteps

\assemblystep{Update the Firmware}
To prepare the motors for programming, open REV Hardware Client 2 and
connect the motor via USB-C. You will more than likely see the device
appear labeled ``Outdated REV Device'' under the hardware tab.

\begin{figure}[H]
\centering
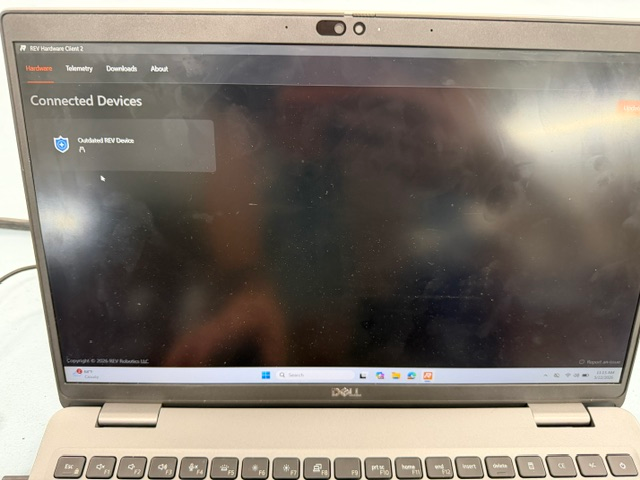
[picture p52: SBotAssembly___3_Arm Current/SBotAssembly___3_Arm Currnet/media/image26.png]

\caption{An ``Outdated REV Device'' listed under the hardware tab.}
\end{figure}

Click on the device and instructions will appear to update the firmware.
Unplug the motor, use a thin object (like a small screwdriver) to press
and hold the Mode button on the motor, and reconnect to the computer.
Then release the Mode button.

\begin{figure}[H]
\centering
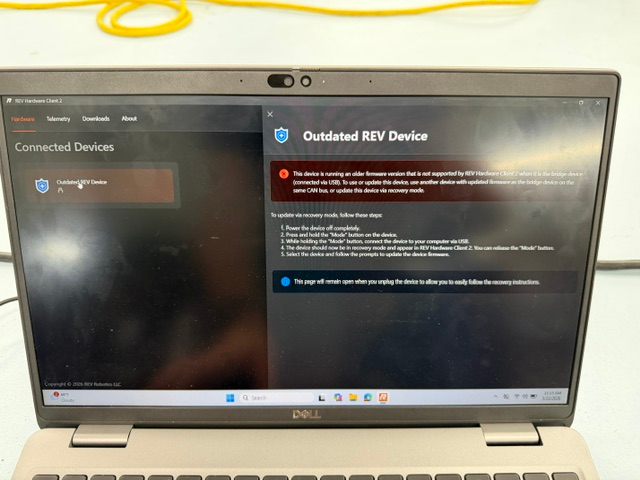
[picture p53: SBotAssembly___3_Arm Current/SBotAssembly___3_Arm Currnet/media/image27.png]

\hfill
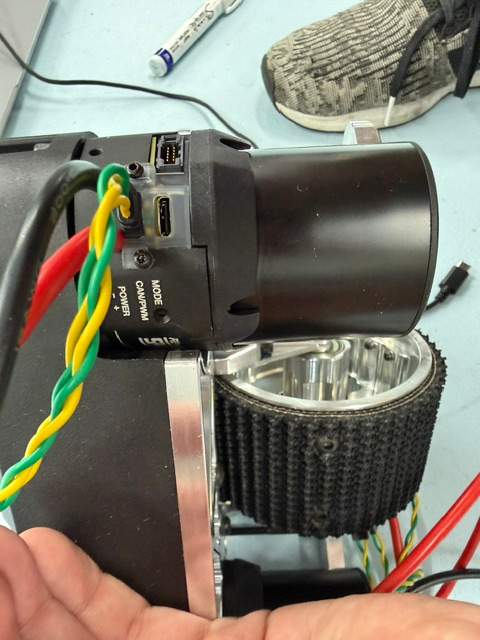
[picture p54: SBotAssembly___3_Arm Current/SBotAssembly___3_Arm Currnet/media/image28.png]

\caption{Holding the Mode button with a thin tool while reconnecting the
motor over USB-C.}
\end{figure}

You will now see the motor label has changed to ``Recovery Device''.
Select SPARK Flex as device type and the latest firmware option and
click Install. After the install, be sure to click on the device, then Configuration, then the 3 dots at the bottom right, then factory reset. Failing to do so may result in the CAN ID being reset after a low battery shutdown.

\begin{figure}[H]
\centering

\caption{Selecting SPARK Flex and the latest firmware on the recovery
device.}
\end{figure}
\clearpage

\assemblystep{Set the CAN ID}
Now you can change the CAN ID. It is recommended to start at a number
then increment with each motor as to avoid having the same ID. It is
also recommended to label the motor with the CAN ID to avoid confusion
later. The numbers used must match the IDs used in arm\_base\_control/configs/basename\_config.yaml file. Either use those values or update the file.

\begin{warningbox}
Make sure only one motor is plugged into the computer at a time while
setting up. As best practice, unplug the motor after the firmware is
successfully updated and then plug back in.
\end{warningbox}

\assemblystep{Configure Motor Settings}
Update the following configurations. Remember to click
the orange save button on the bottom right.

\rowcolors{2}{gray!10}{white}

\begin{table}[H]
\centering
\renewcommand{\arraystretch}{1.35}
\begin{tabularx}{\textwidth}{l X l}
\toprule
\rowcolor{sbotblue!15}
\textbf{Tab} & \textbf{Setting} & \textbf{Value} \\
\midrule
Basic & Idle Mode & \textbf{BRAKE} \\
Closed Loop Control & Closed Loop Control Sensor & \texttt{MAIN\_ENCODER} \\
Closed Loop Control Slot 0 & P0 & \texttt{Steer Motor: 0.5, Drive Motor: .119} \\
\bottomrule
\end{tabularx}
\caption{Required motor controller configuration settings.}
\end{table}

A complete list of configuration settings can be found in Appendix A.

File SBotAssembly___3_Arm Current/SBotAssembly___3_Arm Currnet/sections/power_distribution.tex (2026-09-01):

\section{Power Distribution Assembly}
\resetassemblysteps

To complete the set up for the encoders, power must first be distributed
to the motors and encoders.

\begin{partsbox}
\begin{minipage}[t]{\linewidth}
\vspace{0pt}
\begin{itemize}
\item
  4 \protect\hyperlink{mk5i-swerve-module-assembly}{Assembled Swerve
  modules}
\item
  1 \href{https://store.ctr-electronics.com/products/pdp-2}{PDP 2.0} --
  \href{https://ctre.download/files/user-manual/PDP\%202.0\%20User's\%20Guide.pdf}{User
  Guide} --
  \href{https://github.com/CrossTheRoadElec/Device-CADs/raw/refs/heads/master/PDP2.0_CAD/PDP\%202.0\%20CAD.zip}{CAD
  File}
\item
  1
  \href{https://store.ctr-electronics.com/products/120-amp-breaker?pr_prod_strat=e5_desc\&pr_rec_id=6ce3ee740\&pr_rec_pid=8010746855597\&pr_ref_pid=8358474383533\&pr_seq=uniform}{120
  Amp Circuit Breaker}
\item
  8
  \href{https://store.ctr-electronics.com/products/auto-resetting-ato-breakers?pr_prod_strat=jac\&pr_rec_id=096140681\&pr_rec_pid=8358474383533\&pr_ref_pid=7922412847277\&pr_seq=uniform}{40
  Amp Auto-Reset Breakers} --
  \href{https://ctre.download/files/datasheet/CTRE\%20Breaker\%20Datasheet.pdf}{Data
  Sheet} - \href{https://ctre.download/cad/25-656640.step}{CAD}
\item
  4
  \href{https://store.ctr-electronics.com/products/auto-resetting-ato-breakers?variant=45044982644909}{10
  Amp Auto-Reset Breakers} --
  \href{https://ctre.download/files/datasheet/CTRE\%20Breaker\%20Datasheet.pdf}{Data
  Sheet} - \href{https://ctre.download/cad/25-656610.step}{CAD}
\item
  1
  \href{https://andymark.com/products/mk-es17-12-12v-sla-battery-set-of-2}{MK
  ES17-12 12V SLA Battery} --
  \href{https://s3.amazonaws.com/docusync-files/cacc1eb873bfa1d6bda7b8a738560a16992dd936cd4f6e119a512326d85e2759/am-0844\%20ES17-12\%20User\%20Guide.pdf}{User
  Guide}
\item
  1
  \href{https://andymark.com/products/6-gauge-12-inch-battery-cable?pr_prod_strat=jac\&pr_rec_id=099dfc460\&pr_rec_pid=8263871365292\&pr_ref_pid=8263859503276\&pr_seq=uniform}{6
  Gauge 12'' Battery Cable} --
  \href{https://s3.amazonaws.com/docusync-files/728a9a02b6997b608f834bc0d313a6780025a444f59a5906b091c7c41b2a654c/am-0009\%20Replacing\%20Wires\%20in\%20a\%20SB50\%20Connector_.pdf}{Replacing
  Wire Guide} -
  \href{https://s3.amazonaws.com/docusync-files/acfa0911a51f1f9ec7a07c8cdab5bda8519f734912ab19342f1d5b9b948663ea/am-4483\%206\%20Gauge\%2012\%20Inch\%20Battery\%20Cable,\%20Flexible\%20EPDM.pdf}{Drawing}
\item
  1
  \href{https://andymark.com/products/robot-power-cable-kit-custom-lengths-up-to-36-in?variant=44493418758316}{6
  Gauge 16'' 9'' Custom Power Cable} (Includes the 120 Amp breaker)
\end{itemize}
\end{minipage}
\end{partsbox}

\assemblystep{Assemble the Power Distribution Panel}
Assemble the Power Distribution Panel (PDP) with the 120A breaker and
power cables as shown.

\begin{figure}[H]
\centering

\caption{The PDP wired with the 120A breaker and power cables.}
\end{figure}

Insert the
\href{https://store.ctr-electronics.com/products/power-distribution-panel-wago-tool?pr_prod_strat=jac\&pr_rec_id=6ce3ee740\&pr_rec_pid=7863766450349\&pr_ref_pid=8358474383533\&pr_seq=uniform}{WAGO}
tool or a sturdy flathead screwdriver into the square hole on the PDP
and tilting the tool upwards to release the clamp to install the power
cables for the motors and encoders in a row on the corresponding colors
on the PDP. Be sure that the cables are stripped 3/8'' on the end before
inserting into the panel. Next to each set of cables, install a 40A fuse
for the motors and the 10A fuse for the encoders.

\begin{figure}[H]
\centering

\hfill

\caption{Installing the motor and encoder power cables with their 40A and
10A fuses.}
\end{figure}

Repeat for each Swerve Module assembly. Also install the 12'' battery
cables on the battery with the provided hardware.

\begin{figure}[H]
\centering

\caption{The 12'' battery cables attached to the battery terminals.}
\end{figure}

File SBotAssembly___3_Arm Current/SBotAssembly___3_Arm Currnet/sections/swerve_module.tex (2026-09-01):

\section{MK5i Swerve Motor Module Assembly}
\resetassemblysteps

\begin{partsbox}
\begin{minipage}[t]{\linewidth}
\vspace{0pt}
\begin{itemize}
    \item 8 \hyperref[sec:motor-assembly]{Assembled Motors}
    \item 4 \href{https://www.swervedrivespecialties.com/collections/all/products/mk5i-swerve-module?variant=51829284602157}{MK5i Swerve Module Kits}
    \item 4 \href{https://andymark.com/products/cancoder-magnetic-encoder?variant=44493487145132}{CANcoder Magnetic Encoders}
\end{itemize}
\end{minipage}
\end{partsbox}

These modules come mostly assembled, but the motors and encoders need to be installed and the gear ratio may need adjusting.

\assemblystep{Change Gear Ratio}

First, looking at the top surface of the module, lightly loosen the
right hand screw on the metallic plate. The left hand screw will need to
then be loosened until it can be lifted and pulled down to gear ratio 1.

\begin{figure}[H]
\centering

\caption{Top of Swerve Module before adjusting gear ratio, default setting is on 2.}
\end{figure}

\assemblystep{Steer Motor Installation}
The first motor will need the hardware kit containing the 1mm thick
washer (or shim), 14T pinion gear, 2mm machine key, and 8mm retaining
ring.

\begin{figure}[H]
\centering

\caption{Steer motor hardware kit: shim washer, 14T pinion gear, machine
key, and 8mm retaining ring.}
\end{figure}

\clearpage
Place the washer on the motor shaft, then install the machine key into
the groove on the shaft. Slide the pinion gear onto the shaft, making
sure to align the key slot on the inside of the gear with the key. To
install the retaining ring, a long ratchet socket and a rubber mallet
can be used.

\begin{figure}[H]
\centering

\hfill

\hfill


\vspace{0.4cm}

\hfill

\hfill

\caption{Installing the pinion gear and seating the retaining ring with a
socket and rubber mallet.}
\end{figure}

\clearpage
Insert the motor assembly in the steering motor slot (side opposite of
the metal gear-ratio plate) through the bottom of the swerve module. Be
sure to leave all cables, ports, and buttons facing outwards and are
accessible. Align three of the mounting holes on the motor controller
with the three mounting points on the module. Use three of the six
provided 10-32 x 1/2'' socket screws to secure the motor assembly.

\begin{warningbox}
Careful not to over-tighten the motor assembly screws.
\end{warningbox}

\begin{figure}[H]
\centering

\caption{The steer motor secured in the module slot opposite the
gear-ratio plate.}
\end{figure}

\clearpage
\assemblystep{Drive Motor Installation}
The second motor will require the R1 drive pinion gear, 2mm machine key,
and the provided 10-32 x 3/8'' button screw (T25 head).

\begin{figure}[H]
\centering

\caption{Drive motor hardware: R1 drive pinion gear, machine key, and
button head screw.}
\end{figure}

Install the machine key into the motor shaft. Insert the motor assembly
into the drive motor slot (side with the metal gear-ratio plate) through
the bottom of the swerve module. Keep motor either perpendicular or if
tilted, leave the shaft slot facing upwards as the machine key may fall
out. Be sure to leave all cables, ports, and buttons facing outwards and
are accessible. Align three of the mounting holes on the motor
controller with the three mounting points on the module. Use three of
the six provided 10-32 x 1/2'' socket screws to secure the motor
assembly. Insert the drive pinion gear, making sure to align the slot
with the machine key. Tighten with the button head screw.

\begin{warningbox}
Careful not to over-tighten the motor assembly screws.
\end{warningbox}

\begin{figure}[H]
\centering

\hfill


\vspace{0.4cm}

\hfill

\caption{Mounting the drive motor and seating the drive pinion gear on
the keyed shaft.}
\end{figure}

\assemblystep{Encoder Installation}

\begin{figure}[H]
\centering

\caption{The CANcoder encoder and its clear plastic cover.}
\end{figure}

Remove the two 4-20 x 3/8'' thread-forming screws from the clear plastic
encoder cover. If there is no magnet inside the module or if the magnet
is loose, insert the magnet and secure with Loctite. Secure the bottom
cover with the two short screws provided with the encoder. Make sure the
rectangular end is facing the wire channel as shown below. Place the
encoder in the bottom cover, followed by the top cover. Secure the top
cover with the other provided screw. Reattach the clear encoder cover.

\begin{warningbox}
Do not over-tighten any screws in this step.
\end{warningbox}

\begin{figure}[H]
\centering

\hfill

\hfill

\caption{Seating the encoder between the bottom and top covers, with the
rectangular end toward the wire channel.}
\end{figure}

\assemblystep{Assemble Remaining Modules}
Repeat all steps in this section until you have 4 assembled swerve
modules.

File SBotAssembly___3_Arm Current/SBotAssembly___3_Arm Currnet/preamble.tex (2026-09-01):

% Page layout
\usepackage[letterpaper,margin=0.85in]{geometry}

% Fonts and encoding
\usepackage[T1]{fontenc}
\usepackage[utf8]{inputenc}
\usepackage{lmodern}
\usepackage{textcomp}

% Graphics and layout
\usepackage{graphicx}
\usepackage{xcolor}
\usepackage{float}
\usepackage{booktabs}
\usepackage{enumitem}
\usepackage{caption}
\usepackage{tabularx}
\usepackage[most]{tcolorbox}
\usepackage[table]{xcolor}
\usepackage{longtable}
% Links
\usepackage[hidelinks]{hyperref}
\usepackage{xurl}
\usepackage{fancyhdr}

% Section styling
\usepackage{titlesec}

\usepackage{tocloft}
\usepackage{textcomp}

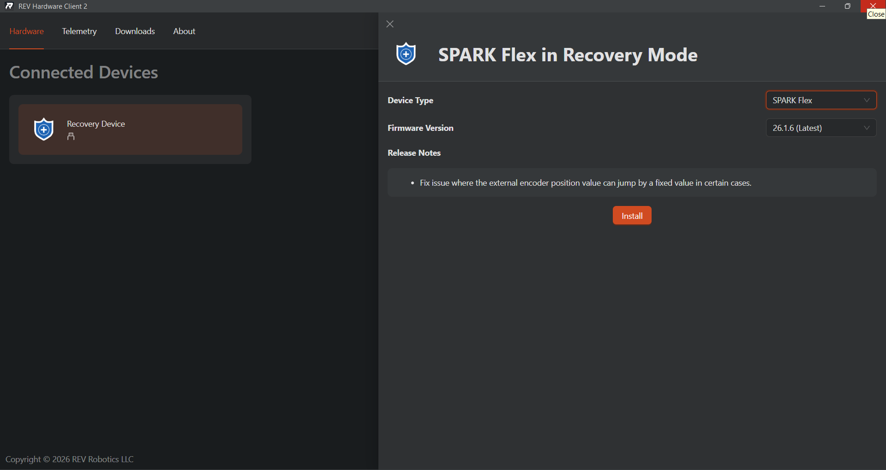
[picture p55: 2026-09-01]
SBotAssembly___3_Arm Current/SBotAssembly___3_Arm Currnet/media/UpdateREV.png

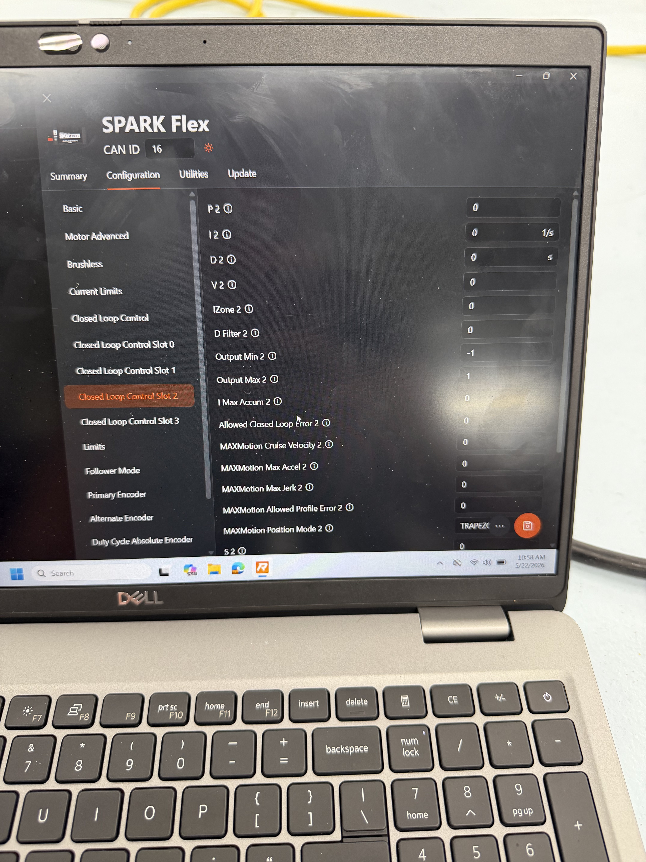
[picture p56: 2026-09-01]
SBotAssembly___3_Arm Current/SBotAssembly___3_Arm Currnet/media/image40.jpg

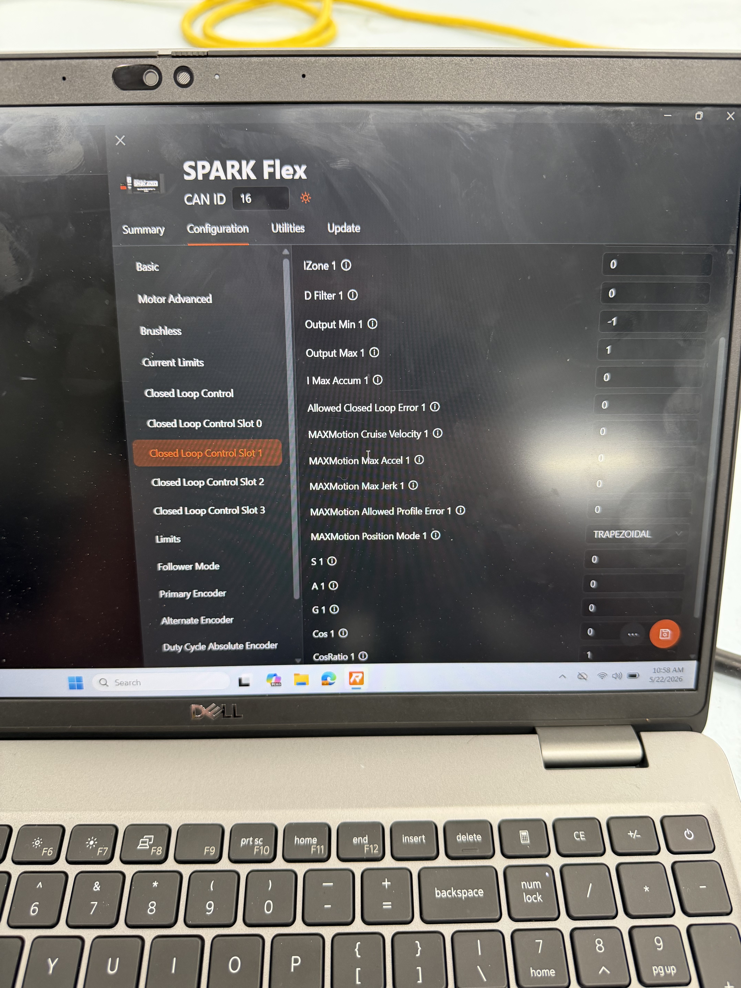
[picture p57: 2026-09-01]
SBotAssembly___3_Arm Current/SBotAssembly___3_Arm Currnet/media/image39.jpg

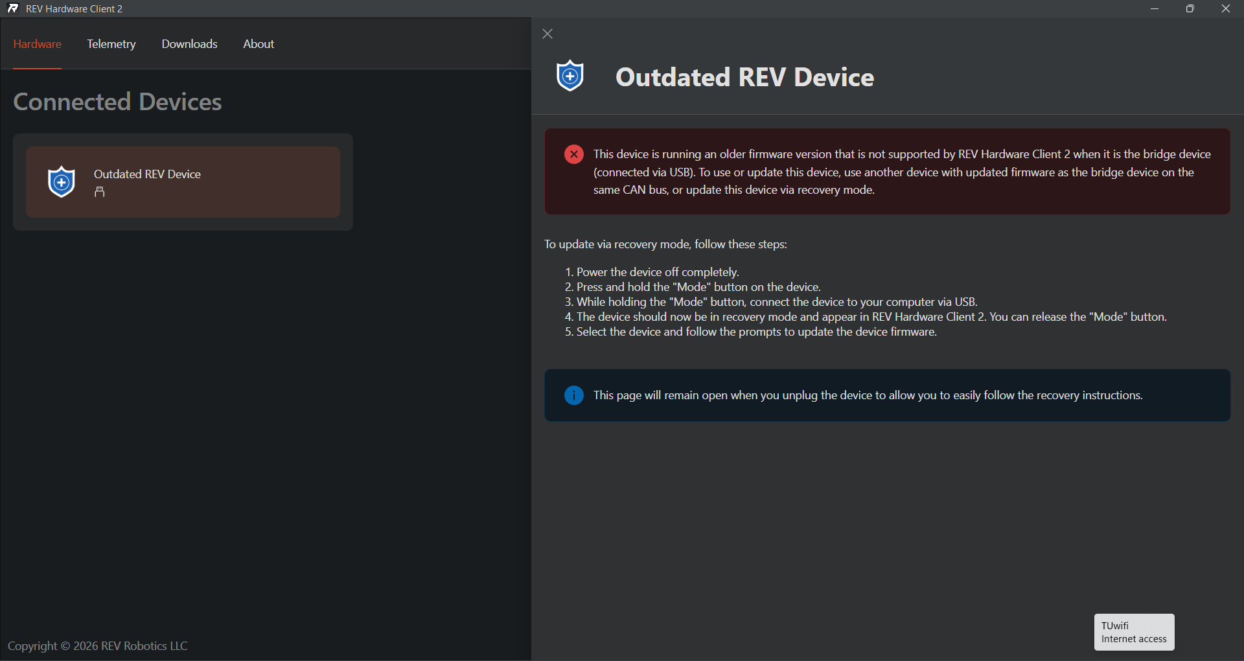
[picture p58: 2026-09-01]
SBotAssembly___3_Arm Current/SBotAssembly___3_Arm Currnet/media/RecoveryModeInstr.png

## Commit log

2026-09-01 Add 2 arm assembly documentation
2026-09-01 Add 3 arm assembly docs
2026-09-01 Add SBOT Hardware CAD
    [135Bracket.SLDPRT, 2020extrusion10mm.SLDPRT, 2020extrusion120.65mmx45.SLDPRT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]
2026-09-01 add remaining CAD files
    [2020extrusion100mm.SLDPRT, 2020extrusion84_85mm.SLDPRT, 2020extrusion86_53mm.SLDPRT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]
